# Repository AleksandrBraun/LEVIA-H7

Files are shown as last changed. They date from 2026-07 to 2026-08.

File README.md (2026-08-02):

# LEVIA H7
Open hardware STM32H743 drone flight controller designed in KiCad.
LEVIA H7 is a six-layer flight controller built around the STM32H743, developed as an open hardware platform for multirotor, fixed-wing and experimental UAV applications.
The repository includes the complete editable KiCad design files, schematics, PCB layout, 3D model, bill of materials and manufacturing files.



Front
Back
Layers

[!WARNING]
LEVIA H7 is currently an unvalidated hardware design.
Prototype bring-up and flight testing are still pending.
Review the design independently before manufacturing or using it in an aircraft.

Render_F
Render_B

## Main features

* STM32H743 high-performance microcontroller
* Six-layer PCB
* Eight motor outputs
* Dual ICM-42688-P inertial measurement units
* DPS368 barometric pressure sensor
* IST8310 magnetometer
* microSD interface for onboard logging
* Analog video interface with AT7456E-compatible OSD
* Digital VTX connector for DJI O3/O4-class systems
* CAN interface with selectable 120 Ω termination
* Dedicated RC input connector
* External I²C and SPI expansion connectors
* Two ESC connectors with current sensing and telemetry inputs
* USB-C interface with ESD protection
* Dedicated 5 V and 9 V switching regulators
* Separate 3.3 V regulators for MCU and sensor domains
* Up to 6S battery input

## Project status

The current files should be considered a pre-production engineering revision, not a flight-qualified product.

## Design overview

LEVIA H7 was designed as a general-purpose H7 flight controller rather than as a clone of an existing commercial board.

The architecture follows common flight-controller conventions where useful for firmware compatibility, including standard STM32 peripheral assignments, SDMMC, USB, motor timers and familiar ESC/VTX interfaces.

The following areas were developed independently for LEVIA H7:

* power architecture;
* component placement;
* PCB outline and mechanical design;
* power-distribution network;
* six-layer stackup implementation;
* signal routing;
* grounding strategy;
* design rules and manufacturing preparation.

Publicly available flight-controller schematics, product documentation and firmware hardware definitions were consulted as engineering references.

## Design references

LEVIA H7 is an original KiCad hardware design.

The MatekH743 ArduPilot hardware definition and publicly available flight-controller documentation were used as references for peripheral allocation, firmware compatibility and common interface conventions.

The power architecture, schematic implementation, PCB placement, mechanical design and routing were developed independently.

## Power architecture

LEVIA H7 uses separate power domains for flight-control electronics and external video equipment.

* 5V_SYS supplies the onboard 3.3 V regulators and external low-voltage peripherals.
* 3V3_MCU supplies the STM32H743 and digital logic.
* 3V3_SENS provides a separate supply for onboard sensors.
* 9V is intended for digital video transmitters.
* USB VBUS can power the system through diode OR-ing for configuration and debugging.

The input power architecture supports batteries up to 6S and includes transient-voltage suppression.

## Sensors

Inertial sensing

LEVIA H7 includes two independent ICM-42688-P IMUs connected to separate SPI buses.

The dual-IMU architecture is intended to support sensor redundancy, comparison and firmware-level failover strategies.

## Environmental sensing

The board includes:

* DPS368 barometric pressure sensor;
* IST8310 three-axis magnetometer.

Additional environmental sensing may be considered in future revisions.

## Interfaces

Motor and ESC connections

LEVIA H7 provides two ESC connectors:

* motors 1–4 with current sensing and ESC telemetry;
* motors 5–8 with an independent current input and telemetry UART.

[!CAUTION]
ESC connector pinouts are not universally standardized. Verify VBAT, GND and signal ordering before connecting an ESC.

## Video

The board supports both:

* analog video with onboard OSD;
* digital VTX systems through a dedicated 9 V connector and UART interfaces.

## Expansion

External interfaces include:

* I²C;
* SPI with two chip-select signals;
* CAN;
* UART-based RC input;
* buzzer;
* LED output;
* auxiliary ADC inputs.

The expansion connectors provide 5 V power, while their digital logic operates at 3.3 V.

## PCB

The PCB uses a six-layer stackup with dedicated ground-reference layers.

The layout was developed and documented progressively, with particular attention to:

* uninterrupted signal return paths;
* switching-regulator current loops;
* IMU power integrity;
* separation of analog and switching nodes;
* USB differential routing;
* SDMMC routing;
* motor and telemetry signal grouping.

## Repository contents
```bash
LEVIA-H7/
├── LEVIA_H7.kicad_pro       KiCad project
├── LEVIA_H7.kicad_sch       Top-level schematic
├── LEVIA_H7.kicad_pcb       PCB layout
├── LEVIA_H7.kicad_dru       Custom design rules
├── *.kicad_sch              Hierarchical schematic sheets
├── LEVIA_H7.pdf             Exported schematic
├── LEVIA_H7.step            3D board model
├── bom/                     Bill of materials
├── jlcpcb/                  JLCPCB manufacturing files
├── nextpcb/                 NextPCB manufacturing files
├── plots/                   PCB images and renders
└── LICENSE.txt              CERN-OHL-S-2.0 license
```

## Viewing the design

The project can be opened locally with KiCad 10.

The schematic and PCB can also be inspected directly in a browser through KiCanvas:

KiCanvas: https://kicanvas.org/?repo=https%3A%2F%2Fgithub.com%2Fpiecol%2FLEVIA-H7

No KiCad installation is required for browser-based inspection.

## Manufacturing

Manufacturing exports are included for convenience, but they should not be treated as production-validated files.

Before ordering:

1. review the schematic and PCB independently;
2. verify connector orientation and pin numbering;
3. confirm all selected component variants and footprints;
4. review assembly substitutions;
5. run the latest ERC and DRC;
6. verify the fabrication stackup and controlled-impedance requirements;
7. inspect Gerber and drill files with an independent viewer.

Please use GitHub Issues for review notes, potential errors and proposed improvements.

## License

LEVIA H7 hardware design files are released under the:

CERN Open Hardware Licence Version 2 — Strongly Reciprocal

See LICENSE.txt for the complete license text.

Any redistribution or modified version must comply with the conditions of CERN-OHL-S-2.0.

## Disclaimer

This project is provided without warranty.

LEVIA H7 is experimental hardware intended for engineering, educational and research use.

UAV systems can cause property damage, injury or loss of the aircraft. Anyone manufacturing, modifying or operating this design is responsible for independently validating its safety and regulatory compliance.

⸻

Designed by Pierluigi Colangeli, PhD

Hardware design · Embedded systems · Open hardware

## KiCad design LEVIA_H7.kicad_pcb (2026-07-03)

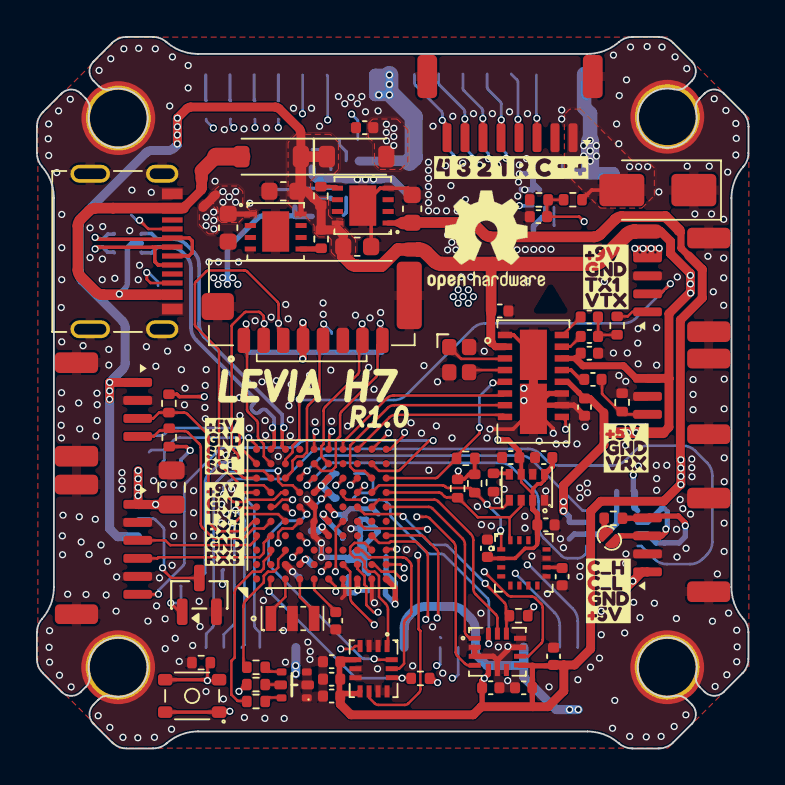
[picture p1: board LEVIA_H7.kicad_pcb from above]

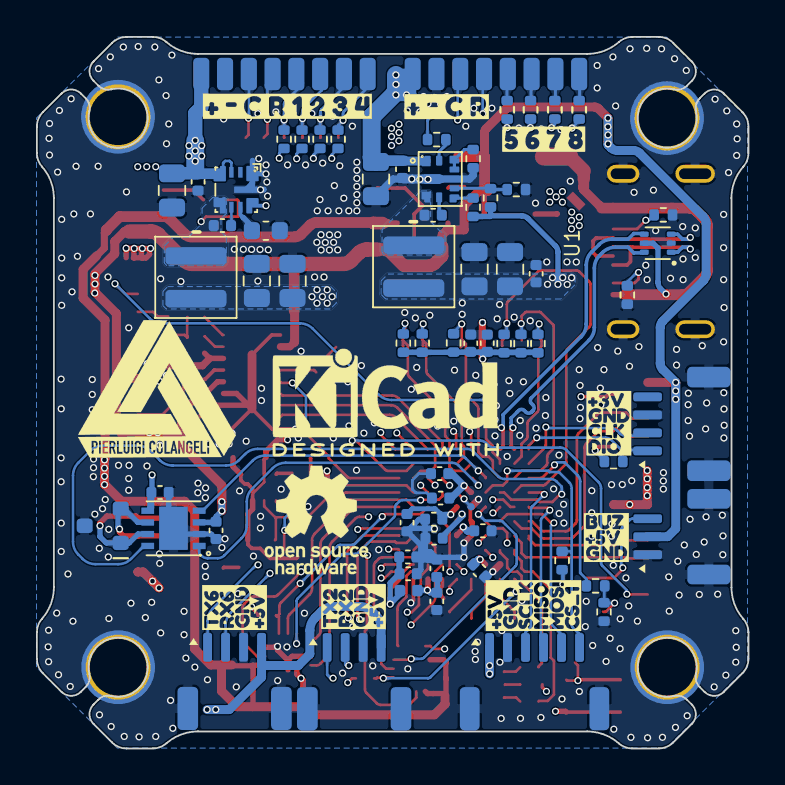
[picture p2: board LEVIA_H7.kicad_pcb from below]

Board: 6 copper layers, 39.5 x 39.5 mm, 170 parts (90 on the bottom side), 119 nets.

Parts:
C1, C4, C5, C6, C9, C10, C15, C16, C17, C20, C21, C26, C28, C33, C34, C35, C38, C39, C40, C43, C44, C47, C48, C49, C50, C54: 100n; C_0402_1005Metric
C2, C12, C41, C42, C51: 4.7u; C_0402_1005Metric
C3, C7, C53: 1u; C_0402_1005Metric
C8, C11: 2.2u; C_0402_1005Metric
C13, C14: 10u; C_0805_2012Metric
C18: 1u; C_0603_1608Metric
C22, C24, C25, C27, C52: 22u; C_0805_2012Metric
C29, C30, C31, C32: 4.7u; C_0603_1608Metric
C36, C37: 10u; C_0402_1005Metric
C45, C46: 10n; C_0402_1005Metric
D1: LED_RGB_EP; LED-ARRAY-SMD_6P-L1.6-W1.6-TL
D2: SMAJ30CA; D_SMA
D3, D4: 1N5819WL; D_SOD-123
D6: PESD2CAN; SOT-23
FB1: 600Ω@100MHz; L_0402_1005Metric
H1, H2, H3, H4: MountingHole_Pad; MountingHole_3.2mm_M3_ISO14580_Pad_TopBottom
J1: TF-028-H265; TF-SMD_TF-021B-H265
JP1: SolderJumper_2_Open; SolderJumper_Mini
L1, L2: 2.2u; L_Coilcraft_XAL4030-XXX
NT1: NetTie_2; NetTie-2_SMD_Pad0.5mm
Q1: AO3400A; SOT-23
R1, R2: 5.1K; R_0402_1005Metric
R3, R8, R10, R19, R20, R21, R27, R28, R32, R35, R36, R37, R38, R39, R40, R41: 10K; R_0402_1005Metric
R4, R5, R6: 220R; R_0402_1005Metric
R7, R9, R15, R29: 100K; R_0402_1005Metric
R11, R34: 1K; R_0402_1005Metric
R12: 16.5k; R_0402_1005Metric
R16: 12.4K; R_0402_1005Metric
R22, R23: 75R; R_0402_1005Metric
R24: 120R; R_0402_1005Metric
R25, R26, R30, R31: 4.7K; R_0402_1005Metric
R42, R43, R44, R45, R46, R47, R48, R49: 10R; R_0402_1005Metric
SW2: RKCGG140SMTRLFS; SW-SMD_4P-L3.0-W2.6-P1.80-LS3.5
TP3, TP4, TP5, TP6, TP7, TP8, TP9, TP10, TP12, TP13, TP14, TP15, TP16, TP17, TP18, TP19: TestPoint_Pad_1.8x0.9mm
TP11: TestPoint; TestPoint_Pad_D1.0mm
U1: USBLC6-2P6; SOT-666-6_L1.6-W1.2-P0.50-LS1.6-BL
U2: STM32H743VIHx; TFBGA-100_8x8mm_Layout10x10_P0.8mm
U3, U8, U10, U13, U18, U24: ZX-SH1.0-4PWT; CONN-SMD_4P-P1.00_MEGASTAR_ZX-SH1.0-4PWT
U4: LMR43620R5RPER; VQFN-9_L2.1-W2.1-P0.50-TL
U5: LMR604303SRAKRQ1; WQFN-9_L2.5-W2.0_RAK0009A
U6, U7: AP7361C-33FGE-7; DFN-8_L3.0-W3.0-P0.65-BL-EP
U9: AT7456ELAH; LGA-16_L6.8-W4.0-P0.65-TL-2EP
U11, U21: ZX-SH1.0-3PWT; CONN-SMD_3P-P1.00_MEGASTAR_ZX-SH1.0-3PWT
U12: SIT1051TK/3; HVSON-8_L3.0-W3.0-P0.65-BL-EP
U14, U15: ICM-42688-P; LGA-14_L3.0-W2.5-P0.50-TL
U16: DPS368XTSA1; LGA-8_L2.5-W2.0-P0.65-TR_DPS368
U17: IST8310; LGA-16_L3.0-W3.0-P0.50-BL_SQ
U19, U20: ZX-SH1.0-6PWT; CONN-SMD_6P-P1.00_MEGASTAR_ZX-SH1.0-6PWT
U22: ZX-SH1.0-8PWT; CONN-SMD_8P-P1.00_MEGASTAR_ZX-SH1.0-8PWT
USB1: HC-TYPE-C-16P-01M; USB-C-SMD_HCTL_HC-TYPE-C-16P-01M
Y1: 8MHz; OSC-SMD_3P-L3.2-W1.3-P1.20-L
Y2: XL7EL89COI-111YLC-27M; Crystal_SMD_2016-4Pin_2.0x1.6mm
kibuzzard-6A40F4B5: G***; kibuzzard-6A40F4B5
kibuzzard-6A40F5CA: G***; kibuzzard-6A40F5CA
kibuzzard-6A40F8CE: G***; kibuzzard-6A40F8CE
kibuzzard-6A40F9B9: G***; kibuzzard-6A40F9B9
kibuzzard-6A40F45A: G***; kibuzzard-6A40F45A
kibuzzard-6A40F56A: G***; kibuzzard-6A40F56A
kibuzzard-6A40F62C: G***; kibuzzard-6A40F62C
kibuzzard-6A40F422: G***; kibuzzard-6A40F422
kibuzzard-6A40F649: G***; kibuzzard-6A40F649
kibuzzard-6A40F691: G***; kibuzzard-6A40F691
kibuzzard-6A40F712: G***; kibuzzard-6A40F712
kibuzzard-6A40F981: G***; kibuzzard-6A40F981
kibuzzard-6A4131D0: G***; kibuzzard-6A4131D0
kibuzzard-6A4131DD: G***; kibuzzard-6A4131DD

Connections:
+3V3_MCU: C31.1, C39.1, C53.1, C54.1, J1.4 (VDD), NT1.1, R5.2, R7.1, R21.2, R25.1, R26.1, R27.1, R28.1, R30.1, R31.1, R32.1, R36.2, R37.2, R38.2, R39.2, R40.2, R41.2, SW2.1, SW2.2, U6.1 (OUT), U12.5 (VIO)
+3V3_SENS: C32.1, C41.1, C42.1, C43.1, C44.1, C45.1, C46.1, C47.1, C48.1, C49.1, C50.1, U7.1 (OUT), U14.5 (VDDIO), U14.8 (VDD), U15.5 (VDDIO), U15.8 (VDD), U16.2 (CSB), U16.6 (VDDIO), U16.8 (VDD), U17.2 (VDD), U17.13 (VDDIO)
+5V: C22.1, C24.1, C26.1, D3.2 (A), L1.2, U4.8 (VOUT/FB)
+5V_SYS: C29.1, C30.1, C33.1, C34.1, C35.1, C40.1, D3.1 (K), D4.1 (K), R19.2, R20.2, U6.8 (IN), U7.8 (IN), U8.4, U9.2 (DVDD), U9.9 (~RESET), U9.12 (AVDD), U9.14 (PVDD), U11.3, U12.3 (VCC), U13.1, U18.1, U19.1, U21.2, U24.4
+9V: C25.1, C27.1, C28.1, C52.1, L2.2, R9.2, R15.2, U10.4, U20.1
/ANALOG VTX/SPI2.CS: R21.1, U2.K8 (PB12), U9.5 (~CS)
/ANALOG VTX/SPI2.MISO: U2.H10 (PB14), U9.8 (SDOUT)
/ANALOG VTX/SPI2.MOSI: U2.G10 (PB15), U9.6 (SDIN)
/ANALOG VTX/SPI2.SCLK: U2.J8 (PB13), U9.7 (SCLK)
/ANALOG VTX/UART1.TX: U2.C9 (PA9), U10.2
/ANALOG VTX/VRX: C38.2, R23.1, U11.1
/ANALOG VTX/VTX: R22.2, U10.1
/BUZZER/BUZZER: R34.1, U2.A8 (PA15)
/BUZZER/BUZZ_PAD-: Q1.3 (D), U21.3
/CAN/CAN1.RX: U2.D8 (PD0), U12.4 (RXD)
/CAN/CAN1.SILENT: U2.C7 (PD3), U12.8 (S)
/CAN/CAN1.TX: U2.E8 (PD1), U12.1 (TXD)
/CAN/CAN1_H: D6.1 (A1), R24.1, U12.7 (CANH), U13.4
/CAN/CAN1_L: D6.2 (A2), JP1.1 (A), U12.6 (CANL), U13.3
/DIGITAL VTX/UART3.RX: U2.J9 (PD9), U20.6
/DIGITAL VTX/UART4.RX: U2.B4 (PB8), U20.4
/DIGITAL VTX/UART4.TX: U2.A4 (PB9), U20.3
/I2C1|SPI3/I2C1.SCL: R30.2, U2.B5 (PB6), U18.4
/I2C1|SPI3/I2C1.SDA: R31.2, U2.A5 (PB7), U18.3
/I2C1|SPI3/SPI3.CS1: R32.2, U2.D7 (PD4), U19.6
/I2C1|SPI3/SPI3.MISO: U2.A6 (PB4), U19.4
/I2C1|SPI3/SPI3.MOSI: U2.C5 (PB5), U19.5
/I2C1|SPI3/SPI3.SCLK: U2.A7 (PB3), U19.3
/MCU/9V_EN: R8.1, U2.D3 (PE5)
/MCU/ADC1_CURR1: TP3.1 (1_1), U2.F2 (PC1), U22.3
/MCU/ADC1_CURR2: TP19.1 (1_1), U2.K3 (PA7)
/MCU/ADC1_VBAT1: C17.1, R10.2, R11.1, U2.F1 (PC0)
/MCU/BOOT0: R3.1, SW2.3, SW2.4, U2.D5 (BOOT0)
/MCU/GYRO1_CLKIN: U2.H8 (PD14), U14.9 (CLKIN)
/MCU/GYRO1_EXTI: U2.G5 (PB2), U14.4 (INT1)
/MCU/GYRO2_CLKIN: U2.G8 (PD15), U15.9 (CLKIN)
/MCU/GYRO2_EXTI: U2.H7 (PE15), U15.4 (INT1)
/MCU/I2C2.SCL: R25.2, U2.J7 (PB10), U16.4 (SCL), U17.1 (SCL)
/MCU/I2C2.SDA: R26.2, U2.K7 (PB11), U16.3 (SDA), U17.16 (SDA)
/MCU/LED0: R4.2, U2.B3 (PE3)
/MCU/LED1: R6.2, U2.C3 (PE4)
/MCU/MOTOR1: R42.1, U2.J4 (PB0)
/MCU/MOTOR2: R43.1, U2.K4 (PB1)
/MCU/MOTOR3: R44.1, U2.G2 (PA0)
/MCU/MOTOR4: R45.1, U2.H2 (PA1)
/MCU/MOTOR5: R46.1, U2.J2 (PA2)
/MCU/MOTOR6: R47.1, U2.K2 (PA3)
/MCU/MOTOR7: R48.1, U2.K10 (PD12)
/MCU/MOTOR8: R49.1, U2.J10 (PD13)
/MCU/NRST: C1.1, U2.E1 (NRST)
/MCU/OSC_IN: U2.C1 (PH0), Y1.1
/MCU/OSC_OUT: U2.D1 (PH1), Y1.3
/MCU/SDIO.CK: J1.5 (CLK), R36.1, U2.C8 (PC12)
/MCU/SDIO.CMD: J1.3 (CMD), R37.1, U2.B7 (PD2)
/MCU/SDIO.D0: J1.7 (DAT0), R38.1, U2.F9 (PC8)
/MCU/SDIO.D1: J1.8 (DAT1), R39.1, U2.E9 (PC9)
/MCU/SDIO.D2: J1.1 (DAT2), R40.1, U2.B9 (PC10)
/MCU/SDIO.D3: J1.2 (DAT3/CD), R41.1, U2.B8 (PC11)
/MCU/SPI1.CS: R27.2, U2.B1 (PC15), U14.12 (CS)
/MCU/SPI1.MISO: U2.J3 (PA6), U14.1 (SDO)
/MCU/SPI1.MOSI: U2.D6 (PD7), U14.14 (SDI)
/MCU/SPI1.SCLK: U2.H3 (PA5), U14.13 (SCLK)
/MCU/SPI4.CS: R28.2, U2.H6 (PE11), U15.12 (CS)
/MCU/SPI4.MISO: U2.K6 (PE13), U15.1 (SDO)
/MCU/SPI4.MOSI: U2.G7 (PE14), U15.14 (SDI)
/MCU/SPI4.SCLK: U2.J6 (PE12), U15.13 (SCLK)
/MCU/SWCLK: U2.A9 (PA14), U3.2
/MCU/SWDIO: R7.2, U2.A10 (PA13), U3.1
/MCU/UART2.RX: U2.C6 (PD6), U24.2
/MCU/UART2.TX: U2.B6 (PD5), U24.1
/MCU/UART6.RX: U2.E10 (PC7), U8.2
/MCU/UART6.TX: U2.F10 (PC6), U8.1
/MCU/UART7.RX: TP18.1 (1_1), U2.H5 (PE7)
/MCU/UART8.RX: TP4.1 (1_1), U2.D4 (PE0), U22.4
/MCU/USB_OTG_P.DN: U1.4 (I/O2), U2.C10 (PA11)
/MCU/USB_OTG_P.DP: U1.6 (I/O1), U2.B10 (PA12)
/MCU/VDD: C2.1, C4.1, C6.1, C7.1, C9.1, C10.1, C12.1, FB1.1, NT1.2, U2.D2 (VDD), U2.F4 (VDDLDO), U2.F5 (VDD), U2.F6 (VDD33_USB), U2.K1 (VDD)
/MCU/VDDA: C3.1, C5.1, FB1.2, U2.H1 (VDDA)
/MOTORS[1-4]/S1: R42.2, TP5.1 (1_1), U22.5
/MOTORS[1-4]/S2: R43.2, TP6.1 (1_1), U22.6
/MOTORS[1-4]/S3: R44.2, TP7.1 (1_1), U22.7
/MOTORS[1-4]/S4: R45.2, TP8.1 (1_1), U22.8
/MOTORS[5-8]/S5: R46.2, TP12.1 (1_1)
/MOTORS[5-8]/S6: R47.2, TP13.1 (1_1)
/MOTORS[5-8]/S7: R48.2, TP14.1 (1_1)
/MOTORS[5-8]/S8: R49.2, TP15.1 (1_1)
/POWER/DJI_EN: R8.2, U5.9 (EN)
/POWER/SW_5V: C20.2, L1.1, U4.5 (SW)
/POWER/SW_9V: C21.2, L2.1, U5.3 (SW)
/USB_OTG.DN: U1.3 (I/O2), USB1.A7 (D-), USB1.B7 (D-)
/USB_OTG.DP: U1.1 (I/O1), USB1.A6 (D+), USB1.B6 (D+)
GND: C1.2, C2.2, C3.2, C4.2, C5.2, C6.2, C7.2, C8.2, C9.2, C10.2, C11.2, C12.2, C13.2, C14.2, C15.2, C16.2, C17.2, C18.2, C22.2, C24.2, C25.2, C26.2, C27.2, C28.2, C29.2, C30.2, C31.2, C32.2, C33.2, C34.2, C35.2, C39.2, C40.2, C41.2, C42.2, C43.2, C44.2, C45.2, C46.2, C47.2, C48.2, C49.2, C50.2, C51.2, C52.2, C53.2, C54.2, D1.1 (RK), D1.2 (GK), D1.3 (BK), D2.1 (A1), D6.3 (Com), H1.1 (1_1), H2.1 (1_1), H3.1 (1_1), H4.1 (1_1), J1.6 (VSS), J1.9 (SH), J1.10 (SH), Q1.2 (S), R1.2, R2.2, R3.2, R11.2, R12.1, R16.2, R23.2, R29.1, R35.2, TP10.1 (1_1), TP17.1 (1_1), U1.2 (GND), U2.C2 (VSS), U2.E4 (VSS), U2.E5 (VSS), U2.E6 (VSS), U2.G1 (VSSA), U2.J1 (VSS), U3.3, U3.5, U3.6, U4.1 (RT), U4.9 (GND), U5.2 (PGND), U6.4 (GND), U6.9 (EXP), U7.4 (GND), U7.9 (EXP), U8.3, U8.5, U8.6, U9.1 (DGND), U9.10 (AGND), U9.11 (PGND), U9.17 (EP1), U9.18 (EP2), U10.3, U10.5, U10.6, U11.2, U11.4, U11.5, U12.2 (GND), U12.9 (EP), U13.2, U13.5, U13.6, U14.2 (RESV), U14.3 (RESV), U14.6 (GND), U14.7 (RESV), U14.10 (RESV), U14.11 (RESV), U15.2 (RESV), U15.3 (RESV), U15.6 (GND), U15.7 (RESV), U15.10 (RESV), U15.11 (RESV), U16.1 (GND), U16.7 (GND), U17.9 (GND), U17.11 (GND), U18.2, U18.5, U18.6, U19.2, U19.7, U19.8, U20.2, U20.5, U20.7, U20.8, U21.1, U21.4, U21.5, U22.2, U22.9, U22.10, U24.3, U24.5, U24.6, USB1.25 (SHIELD), USB1.26 (SHIELD), USB1.27 (SHIELD), USB1.28 (SHIELD), USB1.A1 (GND), USB1.A12 (GND), USB1.B1 (GND), USB1.B12 (GND), Y1.2, Y2.2 (G), Y2.4 (G)
unnamed: C36.2, C37.2, R22.1
unnamed: D1.4 (BA), R4.1
unnamed: D1.5 (GA), R5.1
unnamed: D1.6 (RA), R6.1
unnamed: JP1.2 (B), R24.2
unnamed: Q1.1 (G), R34.2, R35.1
unnamed: TP11.1 (1_1), U2.F7 (PDR_ON)
unnamed: C20.1, U4.6 (BOOT)
unnamed: C18.1, U4.7 (VCC)
unnamed: C21.1, U5.4 (BOOT)
unnamed: R15.1, R16.1, U5.6 (FB)
unnamed: R12.2, U5.7 (MODE/SYNC), U5.8 (RT)
unnamed: R9.1, U5.5 (PG)
unnamed: R19.1, U6.5 (EN)
unnamed: R20.1, U7.5 (EN)
unnamed: U9.3 (CLKIN), Y2.1
unnamed: C37.1, U9.15 (SAG)
unnamed: C38.1, U9.13 (VIN)
unnamed: C36.1, U9.16 (VOUT)
unnamed: U9.4 (XFB), Y2.3
unnamed: R29.2, U16.5 (SDO)
unnamed: C51.1, U17.10 (C1)
unnamed: R1.1, USB1.A5 (CC1)
unnamed: R2.1, USB1.B5 (CC2)
VBAT: C13.1, C14.1, C15.1, C16.1, D2.2 (A2), R10.1, TP9.1 (1_1), TP16.1 (1_1), U4.3 (EN/UVLO), U4.4 (VIN), U5.1 (VIN), U22.1
VBUS: D4.2 (A), U1.5 (VBUS), USB1.A4 (VBUS), USB1.A9 (VBUS), USB1.B4 (VBUS), USB1.B9 (VBUS)
VCAP: C8.1, C11.1, U2.E7 (VCAP), U2.F8 (VCAP)

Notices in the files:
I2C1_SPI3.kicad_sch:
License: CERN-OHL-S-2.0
